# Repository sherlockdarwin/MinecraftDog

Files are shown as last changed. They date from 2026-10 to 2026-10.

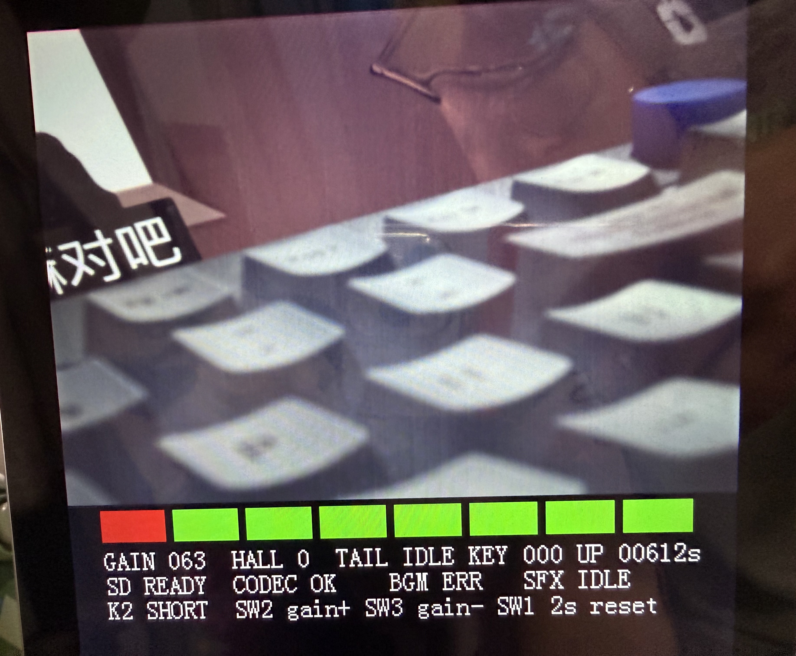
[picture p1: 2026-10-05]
显示屏显示的.JPG

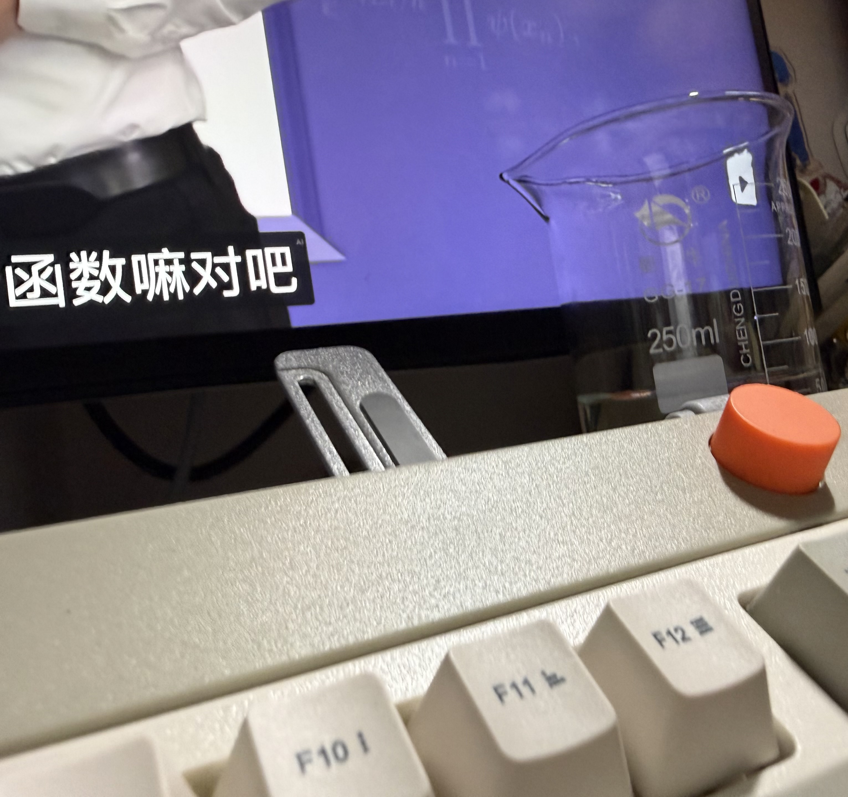
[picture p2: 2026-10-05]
现实.JPG

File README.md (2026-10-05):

# MinecraftDog：基于安路 PH1P35 的跟随避障机器狗

> 2026 嵌入式芯片与系统设计竞赛 · FPGA 赛道（安路选题二）｜TD 6.2.1 + Verilog｜更新 2026-10-05（晚）

---

## 0. AI 交接（新会话先读这一节）

**当前状态**：TD 工程 `mcproject_code/MinecraftDog_FPGA.al`（PH1P35MDG324-3，顶层 `mctop`）。2026-10-05 第一次接屏 + 相机 + 尾巴 + 霍尔上板：**屏幕花屏（竖条纹、字被压扁、整屏抖）、尾巴上电没回中、霍尔 = 1 尾巴也不动**。已按下面改完（仿真全部通过、TD 完整流程通过），**还没再上板**。

**已完成**（统一说明；每块的文件、接线、用法、排错在对应文档里）：

| 模块 | 内容 | 文档 |
| --- | --- | --- |
| 视频通路 | IMX415 → MIPI 4 lane → 取窗 800×560 → 去马赛克 + 白平衡（逐帧算增益）→ DDR2 四缓冲 → 10.1" 800×1280 DSI 屏；竖屏，**上半相机 / 中间状态带（8 个状态方块 + 3 行黑底白字）/ 下半留给避障**；DSI 水平消隐照抄厂商例程；3 个 LED 指示初始化进度 | `src/doc/video_pipeline.md` |
| 人机 | 三键：SW2 / SW3 短按 = 相机增益 ±1；SW1 按住 2 秒整机复位（没有翻页、没有音频页） | `src/doc/hmi_tail.md` |
| 尾巴 | ZDT X42S 步进电机（UART **只发不收**）：上电约 1 秒自动**单圈就近回零**（驱动器转到它存的零点 = 正中）、摇摆一个来回 | 同上 |
| 霍尔 + 行为层 | 霍尔传感器（磁铁靠近 = 1）判断喂食：尾巴摇一个来回，磁铁还在就再摇一个来回；同时进食音效播一遍（播放中不重复触发） | 同上 |
| 音频 | TF 卡 WAV → ES8388 → 喇叭口：`1.wav` 背景音乐上电自动循环（J12 左）、`2.wav` 进食音效（J11 右）、`3.wav` 狗叫（预留）；两路同时播；音量最大；8~48.8 kHz 自动重采样；没有按键操作 | `src/doc/audio.md` |
| 接线 | 步进 TX（只一根线）、霍尔输入接哪些脚，怎么改脚 | `src/doc/pinout.md` |

**验证状态**

- 仿真：20 个测试台（含最慢的 `tb_top` / `tb_audio` / `tb_fb`）在最终文件上全部通过（2026-10-05）。这次新写 / 重写的（白平衡、尾巴、文字面板、台架、串口）都做过突变检查（故意改坏 RTL，看测试台会不会报错），没抓到的都是等价突变，记在 `hmi_tail.md` §7。
- TD 完整流程（综合 + 布局布线 + bit）：**SWNS +1.105 ns、HWNS +0.020 ns，0 违例**；**slice 52%**（上一版 75%）、LUT 47%、寄存器 26%、ERAM 38%、DSP 20%；bit 在 `src/boot/MinecraftDog_FPGA.bit`。省下的 23 个百分点几乎全来自白平衡（原来每个像素都做两次流水线除法，改成每帧算一次）。
- **屏幕**：改的是最可疑的那处（水平消隐），**初始化脚本是否匹配这块屏仍没验证**；还花屏就要商家的初始化代码（`video_pipeline.md` §6）。

**已删除（记录）**：
- 轮子电机：曾经做过 TB6612 双路电机驱动 + 双编码器测速 + 底盘动作命令 + 台架底盘页；轮子控制改放在另一块单片机上，已全部删除。旧版本在 git 提交 `a8d9f01`「有电机」。
- 台架音频页（2026-10-05）：翻页、选曲 / 播放 / 停止、2 秒测试音、背景音乐开关，以及屏幕上的音频页（错误码、缺数据次数、曲目号）。规则已定，不用在板上调；`mc_audio` 的 `I_bgm_en` / `I_sfx_stop` / `I_sfx_tone` 端口和播放器里的测试音一起删了。
- 步进驱动器的串口接收（2026-10-05）：只留 FPGA → 驱动器一根线，`mc_uart_rx` 和应答计数删了；尾巴的「复位 / 标定零点 / 停止」命令口也删了（只剩摇摆 + 上电自动回零）。
- 白平衡的两个流水线除法器（`divider` IP）：被「每帧算一次」的小除法器替代。

**待办**：见 §3。

**规则**

1. 工具：TD（综合、布局布线、下载、ChipWatcher），Verilog-2001（厂商 MIPI 封装用 SystemVerilog）。仿真用 Icarus Verilog（用户已同意安装：`winget install Icarus.Verilog`；换机器装之前先问）：`bash tools/sim.sh` 跑 `src/sim/` 的测试台，默认的 17 个约 25 分钟，跳过最慢的 `tb_top`（约 15 分钟）、`tb_audio`（约 30 分钟）、`tb_fb`（约 2 分钟）；`ALL=1` 全跑（顺序约 1.2 小时）；长仿真放后台，多个并行时各设 `SIM_OUT=<目录>`。厂商的 MIPI 收发、ISP、DDR 控制器没有仿真，靠复用已验证模块 + `tools/td_build.sh` + 上板后用 LED / 状态方块 / ChipWatcher。
2. TD 开着工程时（`mcproject_code/.lock.f` 存在）**不要改 `.al`，不要移动 / 重命名已加入工程的文件**，否则 TD 可能用内存里的版本覆盖；只改文件内容没问题。
3. 在 `src/` 下增删文件后：关 TD → `bash tools/gen_al.sh` → `bash tools/td_build.sh`（在临时目录跑，TD 开着也能用）。**新增 RTL 必须配测试台**（`src/sim/tb_*.v`，并在 `tools/sim.sh` 的 `rtl_for` 登记），而且要做**突变检查**：故意改坏一处，测试台必须 FAIL；接线层（顶层把模块连起来）也要测；确认突变真的改到了；分清"测试台漏洞"和"等价突变"；测试台超时设短（改坏的 RTL 常常卡死）。
4. IP 放 `src/ip/<名>/`（TD 的 Tools → IP Catalog 生成；厂商 IP 整个目录原样复制，目录名不能改）。唯一手改：`w8_d1024_rom` 的 `INIT_FILE` 指向我们的 mif；屏幕初始化脚本改 `rtl/video/disp/panel/ili9881c_k101_init.txt` 后运行 `make_rom.ps1`。
5. 厂商模块尽量不改，改了记进 `video_pipeline.md` §9；自写模块加 `mc_` 前缀，一个文件一个模块，文件名 = 模块名。
6. 编码：UTF-8；厂商源码注释多为 GBK（读之前 `iconv -f GBK -t UTF-8`）；含中文的 PowerShell 5.1 脚本必须带 UTF-8 BOM。
7. 命名沿用米联客：`I_` 输入、`O_` 输出、`IO_` 双向、`S_` 内部信号、`_n` 低有效。
8. 时序逻辑只用 `<=`。自己的模块用异步复位、同步释放（`mc_rst_sync`）；厂商模块直接接 PLL lock。跨时钟域：单比特 `mc_sync_bits` 打两拍，多比特用异步 FIFO 或握手。
9. 周期性任务（PID、串口解析、按键扫描）用 `mc_tick` 的节拍脉冲做使能，不要另写分频计数器，不要造门控时钟。
10. TD 的坑：**TD 的工作目录必须是工程目录 `mcproject_code/`**——双击 `MinecraftDog_FPGA.al` 打开，或先 `cd mcproject_code` 再 `td.exe MinecraftDog_FPGA.al`；从开始菜单启动再 File → Open 的话，TD 找不到 DDR2 IP 自带的约束（生成的 `settings.cfg` 里没有 `IpADCList`，命令行实测工作目录不对就是这样），综合报 `SYN-8534 Can not get the inst ... please add inst constraint`（`tools/td_build.sh` 不受影响）；输入脚的 adc 不能写 `DRIVESTRENGTH`；DDR 端口 `ddr_cke / ddr_odt / ddr_cs_n / ddr_ck_p / ddr_ck_n` 必须声明成 `[0:0]`；加密的 DSI 打包核里藏着 `w32_d512_fifo`、`w8_d1024_fifo` 两个 IP，漏了会报 "black box"；`.al` 里每个文件的 `CompileOrder` 不能重复。
11. 取窗硬约束：`CROP_Y0` 必须是奇数（Bayer 相位）；`WIN_W` 是 16 的倍数且 `WIN_W×WIN_H` 是 1280 的整数倍（帧缓存突发长度）。
12. **用词：Verilog 里没有"写函数然后调用"。** 功能写成**模块**，用的地方**例化**；"调用" = 给输入端口一个命令（电平，或脉冲 + `busy/done`），"返回值" = 读输出端口；`delay_ms` 式阻塞等待 = 状态机里数 `mc_tick` 节拍。接口速查：`hmi_tail.md` §5。
13. 按键：SW2 / SW3 短按 = 相机增益 ±1，**SW1 按住 2 秒整机复位**，其余没有功能（`hmi_tail.md` §4）。
14. 屏幕版面（上半相机窗口、中间状态带、下半避障区）只在 `mctop.v` 配置区定义（只做竖屏）。版面图：`video_pipeline.md` §4。**DSI 的水平消隐（24/136/160）和厂商例程一致，不要压缩**（压缩过一次，上板花屏）。
15. 对用户：用中文，概念用 STM32 类比，给 TD 的具体菜单步骤；文档精简；写完代码要讲清架构、每个文件做什么、怎么接线。

---

## 1. 比赛和硬件

| 项 | 内容 |
| --- | --- |
| 截止 | **2026-11-04 18:00** 线上提交作品报告 + 视频（www.socchina.net）；决赛 11-20 ~ 22，南京，现场有 FPGA 编程考核 |
| 选题 | 安路选题二：PH1P35 实时图像处理，结合移动平台，根据识别结果做外部控制 |
| 规则 | 不能用非安路 FPGA；主控和算法放 FPGA（片内 RISC-V 也可）；UWB、超声波等成品模块只当传感器 |
| 得分点 | MIPI 采集 + 实时显示、至少一种 FPGA 图像算法、OSD（**必须带"安路"Logo**）、长时间稳定运行；加分：目标跟踪 + 坐标叠加、运动检测、延迟可视化、AE/AWB、多算法切换 |

| 硬件 | 说明 |
| --- | --- |
| 板子 | 米联客 MLKPAI-F02 底板 + FC02 核心板：PH1P35MDG324（LUT4 38k、DFF 42k、DSP 40、ERAM 108×20 Kb）、合封 DDR2 512 Mb、MIPI D-PHY ×2（CSI 收 / DSI 发）、CEP 排针 36 个 3.3 V IO；没有 HDMI；Type-C 下载 / 供电 5V/3A |
| 摄像头 | MLK-CAM002-IMX415：MIPI CSI-2 4 lane RAW10；I2C 0x34；INCK 24 MHz；2×2 binning 1920×1080，每 lane 891 Mbps；M12 镜头 f 4.2 mm，视场 H72°/V56° |
| 屏幕 | 米联客 10.1" MIPI DSI：**800×1280 竖屏**，ILI9881C，4 lane |
| 尾巴 | ZDT X42S 第二代闭环步进电机（串口 TTL 版，Emm 固件，UART 115200 只发，地址 1，16 细分），摆幅 ±30°；上电单圈就近回零 |
| 轮子 | **不在 FPGA 里**：轮子的电机驱动、编码器和速度环都放在另一块单片机上 |
| 音频 | TF 卡 → 板载 ES8388 → 板载 TT8642 功放 → 喇叭口 J12（左）/ J11（右）或耳机口 J3 |
| 传感器 | 霍尔模块（喂食检测，磁铁放在食物模型上）；UWB 模组、超声波：**待资料，先不写** |
| 电源 | 2S 锂电池 → 5 V/3 A 降压给开发板；所有地连在一起（包括轮子单片机） |

管脚、接线、改脚：`pinout.md`；时钟：PLL `mcsys_pll` 输入 25 MHz，输出 100 MHz（主逻辑）/ 24 MHz（相机）/ 52.173913 MHz（DSI 参考）/ 10 MHz（面板 LP 配置），各时钟域之间按异步处理（`mc_timing.sdc` 的 `set_clock_groups`）。

和 C 工程（TI2026H）的对应：`main()` + SysConfig → `mctop.v` + `pin/mc_pin.adc`；定时器 + 任务表 → `mc_tick` 脉冲 + 各自用 tick 做使能的 always 块（并行，互不阻塞）；`Key()` → `mc_key`；`OLED_Show*` → `mc_osd_dash`（版面由 `tools/gen_osd_dash.pl` 生成）；`Stepper_*` → `mc_tail`（只发不收）。

## 2. 数据流

```
IMX415 ─MIPI─► 取窗 → 去马赛克 → AWB ─► DDR2 四缓冲 ─► mc_mixer（上半相机 + 状态带）─► DSI ─► 屏幕             ◄ 已完成
                └─► 避障分析（并联一路抽取，160×90 流水线）→ 16 个扇区的可通行深度 → 屏幕下半：处理画面 + 画框   ◄ 待办
霍尔 ─► mc_hall ─► mc_behavior ─┬─► mc_tail（尾巴，UART 只发）◄ 已完成
                                └─► mc_audio（进食音效）       ◄ 已完成
UWB / 超声波 ─► （距离、方位）─► mc_behavior / 决策 ─► 速度 / 方向命令 ─► 轮子单片机（接口待定）                ◄ 待办
```

## 3. 待办

1. **上板验证**（按顺序）：屏幕（这次改了水平消隐；还花屏就要商家这块屏的初始化代码，`video_pipeline.md` §6）→ 相机出图（稳定、不卡顿）→ 尾巴（先在驱动器菜单设回零零点，`hmi_tail.md` §3；方向与摆幅 `TAIL_LEFT_CCW`、`TAIL_GEAR_X100`）→ 霍尔 → 音频（音量最大，破音就把 `AUD_SPK_VOL` 改回 30）→ 摄像头安装高度和俯角。
2. **避障模型 + 画框（屏幕和相机稳定以后再做，还没开始）**：只做避障必需的图像运算（§4），处理后的画面 + 可通行框画在**屏幕下半部分**（v 720~1279，800×560，和相机窗口一样大；`mc_mixer` 叠加）；OSD 要带安路 Logo。
3. **UWB（等资料齐了再写）**：串口解析出距离 / 方位；接 `mc_behavior`：距离 < 5 m 时摇尾巴（`I_near`）；检测不到 / 太远时播 `3.wav` 狗叫（`I_bark`）；跟随控制。
4. 超声波近距兜底。
5. 决策状态机（安全 > 避障 > 跟随 > 报警），输出方向 / 速度命令给轮子单片机（接口待定，串口最简单；速度环 PID 在那块单片机上）。
6. 小改进（有余力再做）：重采样改线性插值；背景音乐循环衔接处的短停顿；屏幕稳定以后把 DSI 提到约 60 Hz（`video_pipeline.md` §7）。
7. **资源**：slice 用了 52%，还剩约 48%（约 10000 个 slice）给避障流水线。大头（综合后 LUT + 进位）：相机接口 `mc_cam_if`（去马赛克 + 白平衡 + MIPI 收）、帧缓存 + DDR2 控制器、音频约 2500（`mc_fat32` 约 1100、两个播放器约 700）、显示接口约 800、文字面板约 250。

## 4. 避障需要的图像运算（只做必要的，其余不管）

方案：单目"地面外观 + 列扫描"（Ulrich & Nourbakhsh 2000），整条链都是行缓存流水线，不占 DDR，PH1P35 放得下（Fast-SCNN 之类分割网络放不下）。前提：地面大致平坦且颜色和障碍不同；摄像头下俯 15° ~ 25°。

| # | 运算 | 干什么 |
| --- | --- | --- |
| 1 | 抽取 + 均值 | 完整视场（取窗之前）→ 2×2 抽取 → 6×6 均值 → 160×90 |
| 2 | RGB → YCbCr（移位加法） | Y 找边缘；Cb / Cr 判断地面颜色（对阴影不敏感） |
| 3 | Sobel 边缘（3×3 窗口，前面可加 3×3 平滑） | 地面和障碍颜色接近时靠边缘分开 |
| 4 | 地面颜色模型 | 画面底部中间梯形区域统计 Cb / Cr 均值 ± 余量；超声波说前方 50 cm 内没东西才更新 |
| 5 | 二值化 | 颜色不像地面 **或** 边缘强 → 障碍 = 1 |
| 6 | 腐蚀 → 膨胀（开运算） | 去掉地砖缝、木纹、噪点 |
| 7 | 列扫描 | 每列从下往上第一个障碍点 → 可通行高度；160 列合并成 16 个扇区取最小 |
| 8 | 行号 → 距离 | 查表（地上每隔 10 cm 做标记，记行号） |
| 9 | 时域平滑 | 和上一帧取最小 / 平均，防闪烁 |
| 10 | 画框 / 色条 / Logo | 每帧消隐期在 16 个扇区深度上找最大矩形（宽度要容得下车身）；`mc_mixer` 逐像素判断是否在框线上；窗口内坐标 = 传感器坐标 − 窗口左上角（`CROP_X0_GRP×4`、`CROP_Y0`）；框坐标从分析时钟域用握手 / 双缓冲交给像素时钟域 |

已有的：去马赛克、白平衡（`awb`）、手动增益（台架第 0 页）。每一步先写测试台（用静态图片作输入）。

## 5. 参考项目和论文

| 项目 / 论文 | 借鉴什么 |
| --- | --- |
| [maojinxiang/FPGA-ANLU-National-First-Prize](https://github.com/maojinxiang/FPGA-ANLU-National-First-Prize)（首奖项目：HX4S20C + OV5640 + 640×480 HDMI，核心 `Main/q3q4/import/udp_cam_ctrl.v`） | 16 种图像效果里**只有灰度、二值化、Sobel、腐蚀、膨胀**直接能用；所有效果放一个模块用选择信号切换、Sobel / 腐蚀 / 膨胀共用 3×3 窗口的结构。它是 EG4 工程，代码不能直接搬；没有地面模型、列扫描、距离换算 |
| Ulrich & Nourbakhsh，*Appearance-Based Obstacle Detection with Monocular Color Vision*（AAAI 2000，[摘要页](https://mlanthology.org/aaai/2000/ulrich2000aaai-appearance)） | 本方案的原型：按颜色外观把每个像素分成"地面 / 障碍"，前方一块地面作参考区、边走边更新 |
| Angelo Jacobo：[FPGA_RealTime_and_Static_Sobel_Edge_Detection](https://github.com/AngeloJacobo/FPGA_RealTime_and_Static_Sobel_Edge_Detection)（MIT） | Verilog 流水线 Sobel：行缓存 + 3×3 窗口 + 阈值的写法（Xilinx 的 PLL / SDRAM 文件不用管） |
| Machado 等，*Vision-based robotics using open FPGAs*（Microprocessors and Microsystems 103，2023，[条目页](https://burjcdigital.urjc.es/items/fd325d26-45aa-4980-aa14-6e47b91387c9/full)） | 开源 Verilog 视觉机器人模块库（图像处理块 + 反应式控制块），演示彩色目标跟随；条目页没给代码仓库链接，要自己再找；"按颜色跟随"可当 UWB 跟随的备份 |
| *A Monocular Vision Sensor-Based Obstacle Detection Algorithm for Autonomous Robots*（Sensors 16(3):311，2016，[全文](https://www.mdpi.com/1424-8220/16/3/311)） | 逆透视映射 + 地面外观模型：对应"行号 → 距离"查表和地面模型（后面的马尔可夫随机场太重，不用） |
| *Real-Time Freespace Segmentation on Autonomous Robots…*（[arXiv 1902.00842](https://arxiv.org/pdf/1902.00842)） | 目标和我们一样（可通行区域）但用神经网络，跑不动；只当"输出长什么样"的参考 |
| Linux 内核 [`panel-ilitek-ili9881c.c`](https://github.com/torvalds/linux/blob/master/drivers/gpu/drm/panel/panel-ilitek-ili9881c.c) | ILI9881C 初始化序列和显示时序的公开参考（本工程用 K101-IM2BYL02 那一份） |
| 安路官方样例 https://pan.baidu.com/s/12hjB7BiAxT3CIVqzh4Amnw（提取码 Q614） | HX1P35A 平台（也是 PH1P35MDG324）的 MIPI、边缘检测、OSD 样例；评分标准在 `../选题/` |

（后四项和 Machado 的条目是检索结果摘要，没有逐个读源码，用之前自己判断。）

## 6. 目录

```
MinecraftDog/
├── README.md
├── tools/        td_build.sh（命令行跑 TD 完整流程）、gen_al.sh（重新生成 .al，TD 要关）、sim.sh（跑测试台）、gen_osd_dash.pl（生成屏幕状态面板 mc_osd_dash.v）、mk_sd_test_image.pl（生成测试用 FAT32 卡镜像）、render_pdf.ps1（PDF 页转 PNG）、gen_font.sh（生成字库）
└── mcproject_code/               TD 工程根目录（MinecraftDog_FPGA.al 在这里）
    └── src/
        ├── rtl/      mctop.v（顶层 + 配置区）、system/（复位、节拍、同步器、长按复位）、hmi/（按键、台架）、comm/（串口发送）、tail/（尾巴）、
        │             sensor/（霍尔）、app/（行为层）、audio/（TF 卡 WAV → ES8388）、video/（cam 相机、rx MIPI 接收、isp、fb 帧缓存、disp 显示接口 + 合成器、osd 文字层）
        ├── ip/       TD 生成的 IP，一个 IP 一个子目录
        ├── pin/      mc_pin.adc（管脚）、mc_timing.sdc（时序）
        ├── sim/      20 个测试台 tb_*.v + stubs/（顶层集成测试用的视频替身、白平衡延迟线 RAM）+ models/（TF 卡、I2C 从机行为模型）
        ├── boot/     验证过的 .bit
        └── doc/      pinout.md 接线｜video_pipeline.md 视频通路 + 版面｜hmi_tail.md 按键 / 台架 / 尾巴 / 霍尔 / LED｜audio.md 音频
```

参考资料（路径相对 `FPGA/reference/`）：`02_F02_FC02_PH1P35/01_start/02_peripheral_demo/02_peripheral_demo/08_csi_dsi_cs500_7cun/`（视频通路底座：MIPI RX、ISP、DDR2、DSI；`td_project/*.sdc` 是多时钟约束范本）；`07_ddr_test`、`09_aud8388_loop`（DDR2 用法、ES8388 配置）；`02_hardware/…/MLKPAI-F02开发平台硬件使用手册.pdf`（管脚表）和 `…/02_原理图/MLKPAI-F02底板.pdf`（P05 AUDIO 页、TF 卡座；渲染某页：`powershell -File tools/render_pdf.ps1 -Pdf <pdf> -Page <页号> -Out <png>`）；`06_MLK-CAM002-IMX415/`（IMX415 配置、4-lane 解包、`摄像头调节心得.docx`）；`显示屏1~3.png`（10.1" 屏的 40P 管脚、尺寸）；`TI2026H题code/`（旧 C 工程：PID、任务调度，可参考参数；轮子单片机那边用得上）。不用看：`XILINX/`、`F20_CM02_3EG_1_1/`、`soc_prj/`（Xilinx 工程）。

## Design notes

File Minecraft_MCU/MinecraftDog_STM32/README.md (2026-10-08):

## MinecraftDog STM32F103RCT6

### 功能

跟随 + 避障的决策全在 FPGA, STM32 只做传感器和电机驱动:

1. **UWB 定位**: 三个基站(左 / 前 / 右)各接一个串口, 中断收字节, 解 0x2001 定位帧(37 字节, XOR 校验)。
   取角度最靠近自己正前方的那个基站, 换算成车体坐标(左负右正)的角度 + 距离; 500 ms 没新数据 = 收不到 UWB。
2. **发给 FPGA**: 有新 UWB 数据就用 DMA 发主人的角度、距离; 收不到 UWB 就发"丢失"。
3. **收 FPGA 的命令**: DMA 环形缓冲收两个轮子的 PWM, 解包后驱动电机。
4. **停车保护**: 收不到 UWB / 200 ms 没收到完整的 FPGA 帧 / FPGA 发来停车, 任何一条成立就关电机锁停车。
5. **电机驱动**: 两路 PWM(9 kHz, 0~8000) + 4 个方向脚, 带死区补偿和方向极性开关。
6. **编码器**: TIM8 / TIM2 硬件计数, 速度和里程函数都在 `encoder.c`, 现在控制里没用到。
7. **按键试电机**: KEY1 前进 3 秒、KEY2 后退 3 秒, 不用接 FPGA。
8. **LED**: 和 FPGA 通 = 1 秒闪一次, 不通 = 快闪。

### 目录

| 位置 | 内容 |
| --- | --- |
| `Core/` `Drivers/` | CubeMX 生成。`main.c` 只在 USER CODE 里调 `bsp_init()` / `Scheduler_Run()` |
| `SYSTEM/` | `AllHeader.h`、`bsp.c`(模块初始化)、`delay.c`(SysTick 微秒延时 + 秒表)、`task.c`(协作式调度表, 1 ms 时基 = `HAL_GetTick()`) |
| `HARDWARE/MLK/` | FPGA 串口 (USART3, DMA 收发), 解包变量在`fpgamlk.c` 顶部 |
| `HARDWARE/UWB/` | 三个 UWB 基站 (USART2 / UART4 / UART5, 接收中断) |
| `HARDWARE/MOTOR/` | 电机 PWM + 方向、编码器 |
| `HARDWARE/KEY/` | KEY1 / KEY2 |
| `ALGORITHM/` | 本地跟随`follow.c`, 已停用, 保留备查 |

OLED 没移植 (STM32 版没留 OLED 引脚)。

### 引脚

| 功能 | 引脚 | 外设 |
| --- | --- | --- |
| FPGA | PB10 TX -> FPGA CEP 脚 4; PB11 RX <- CEP 脚 3; GND 接 CEP 脚 2 | USART3, RX DMA1 CH3 (Circular), TX DMA1 CH2 |
| UWB 左 / 前 / 右 | PA3 / PC11 / PD2 收 (PA2 / PC10 / PC12 发, 预留) | USART2 / UART4 / UART5, 接收中断 |
| 左 / 右轮 PWM | PA6 / PA7 | TIM3 CH1 / CH2, 9 kHz, 0~8000 |
| AIN1 AIN2 BIN1 BIN2 | PB12 PB13 PB14 PB15 | GPIO 输出 |
| 左编码器 A / B | PC6 / PC7 | TIM8 编码器 |
| 右编码器 A / B | PA15 / PB3 | TIM2 编码器 (部分重映射, 要 SYS = Serial Wire) |
| KEY1 / KEY2 | PC9 / PC8 | 输入上拉, 按下 = 低 |
| LED | PA8 | GPIO_Output, Label =`LED` (没有这个 Label 时 `Task_LED` 什么也不做) |
| SWD | PA13 / PA14 | |

### 任务

| 任务 | 周期 | 做什么 |
| --- | --- | --- |
| `Task_UWB_Poll` | 5 ms | 解析 UWB 帧 |
| `Task_FPGA_Rx` | 5 ms | 解 FPGA 帧 (`#+3000-0500*` / `#S*`); 串口出错时重启接收 DMA |
| `Task_Motor_Drive` | 5 ms | 按 FPGA 命令驱动电机; UWB 丢 / 200 ms 没帧 /`#S*` 立即停车; 按键试电机 |
| `Task_FPGA_Tx` | 20 ms  | 新 UWB 数据发`$l12350&`, 收不到 UWB 发 `$S&` (100 ms 重发) |
| `Task_Key_Scan` | 10 ms  | 按键消抖 |
| `Task_LED` | 100 ms | 和 FPGA 链路通 = 1 秒闪一次, 不通 = 快闪 |

**试电机方向** (不用接 FPGA): KEY1 = 两轮 +3000 前进 3 秒, KEY2 = 两轮 -3000 后退 3 秒, 测试中再按任一键停。
哪个轮子转反了, 改 `motor.h` 的 `MOTOR_L_DIR_INVERT` / `MOTOR_R_DIR_INVERT`。

### 和 FPGA 的通讯协议

UART 115200 8N1, ASCII, **位数不够前面补 0**。
接线: FPGA CEP 脚 3 (FPGA 发) -> **PB11**; **PB10** -> CEP 脚 4 (FPGA 收); GND 接 CEP 脚 2。

| 方向 | 帧 | 含义 | 什么时候发 |
| --- | --- | --- | --- |
| STM32 -> FPGA | `$` + `l`/`r` + 角度 2 位 + 距离 3 位 + `&` | 主人在左(`l`) / 右(`r`) 多少度、多远(cm)。例`$r00150&` = 正前方、150 cm。角度超过 99° 发 99, 距离超过 999 cm 发 999 | 每次有新 UWB 数据(最快 20 ms 一帧) | |
| STM32 -> FPGA | `$S&` | 收不到 UWB | 刚丢时立刻发, 之后每 100 ms 一帧 |
| FPGA -> STM32 | `#` + 左轮(符号 + 4 位) + 右轮(符号 + 4 位) + `*` | 两个轮子的 PWM, 正 = 前进, 满量程 8000 (就是`PWM_Control_Car(左, 右)` 的参数)。例 `#+3000-0500*` = 左 +3000、右 -500 | FPGA 每 20 ms 一帧 |
| FPGA -> STM32 | `#S*` | 马上停车 | 停车期间每 20 ms 一帧 |

- 超时: FPGA 那边 300 ms 收不到 `$…&` 就当 UWB 丢了; STM32 这边 200 ms 收不到完整的 `#…*` 就停车。
- 解包规则 (`fpgamlk.c`): 收到 `#` 就重新开始一帧, 帧外的字节丢掉; `S` 大小写都行;
  格式不对的整帧丢掉 (计数在 `g_fpga_error_count`); 超过 ±8000 的按 ±8000 算。
- 解包结果 (`fpgamlk.c` 顶部, 调试时在 Live Expressions 里看):

- [ ] 变量含义`g_fpga_left_pwm` / `g_fpga_right_pwm`最近一帧的左 / 右轮命令`g_fpga_stop`1 = 最近一帧是`#S*` (上电还没收到帧时也是 1)`g_fpga_last_ms` / `g_fpga_frame_count`最近一帧的时刻 / 累计帧数`g_fpga_error_count` / `g_fpga_uart_error_count`格式错的帧数 / 串口硬件错误次数 (每次都会自动重启接收)`g_fpga_uwb_lost` / `g_fpga_tx_angle_deg` / `g_fpga_tx_distance_cm` / `g_fpga_tx_count`最近发给 FPGA 的内容和累计发出的帧数

### CubeMX 里不能改掉的设置

- USART3_RX DMA Mode = **Circular**; USART3 global interrupt **打开** (DMA 发送靠它结束, 串口出错也靠它报告)。
- USART2 / UART4 / UART5 global interrupt 打开。它们的中断在 `stm32f1xx_it.c` 的 USER CODE 0 里直接调
  `UWB_IRQHandler()` 后 `return`, 不走 HAL。
- TIM3 Period = 7999 (PWM 满量程 8000, 和 FPGA 发来的命令同一个刻度)。
- 重新生成代码时 Project Manager 里要保持 "Keep User Code when re-generating"。

### 工程设置 (CubeMX 重新生成后还在)

- `.cproject` 的源码目录: `Core` `Drivers` (CubeMX 自带) + `ALGORITHM` `HARDWARE` `SYSTEM`。
- include 路径: `../` `../SYSTEM` `../HARDWARE` `../HARDWARE/MOTOR` `../HARDWARE/UWB`。
- CubeMX 重新生成时会把"整个工程根目录当源码"这种设置删掉, 只保留按文件夹加的源码目录,
  所以 **新建 .c 文件要放进这几个文件夹里**, 别放工程根目录 (放了不会被编译)。
- 新建文件夹要编译: Properties -> C/C++ General -> Paths and Symbols -> Source Location -> Add Folder。
- 重新生成前先关掉编辑器里打开的 `main.c` 等 CubeMX 文件, 生成完在工程上按 F5 刷新;
  不然编辑器里的旧内容一保存, 就会把 USER CODE 里的 `bsp_init()` / `Scheduler_Run()` 盖掉。

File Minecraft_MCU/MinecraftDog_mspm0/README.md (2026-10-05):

## MinecraftDog MSPM0G3507 base project

This project provides a ready-to-call base layer for the drive motors,
quadrature encoders, SSD1306 OLED, and three ALX-AOA-FIT UWB anchors. All
periodic work is registered in `task.c`; `main()` only initializes the BSP and
runs the cooperative scheduler.

### Follow controller

`ALGORITHM/follow.c` implements a differential-drive distance/heading
controller. `Task_Follow_Control` runs it every 20 ms. The distance error
produces forward PWM, the signed UWB azimuth produces turning PWM, and the two
commands are mixed into left/right wheel commands. Forward PWM increases with
distance and is reduced as the heading error grows; at 90 degrees the robot
pivots instead of driving farther away. A command ramp limits sudden speed
changes.

The controller is disabled after reset for safe bench testing. Start and stop
it explicitly:

```c
Follow_Enable(1U); /* allow automatic following */
Follow_Enable(0U); /* immediate stop and motor lock */
```

Two public condition flags are ready for later FPGA communication:

- `g_follow_stop_flag == 1`: fresh target distance is at most 300 cm.
- `g_follow_lost_flag == 1`: target is missing/stale or farther than 2000 cm.

Both conditions stop the motors immediately. The gains, limits, and distance
thresholds are centralized in `ALGORITHM/follow.h` for vehicle tuning.

### Keys

Three active-low keys are sampled by `Task_Key_Scan` every 10 ms. The driver
uses a non-blocking state machine with 20 ms debounce and an 800 ms long-press
threshold. A long press is reported once while held and is not also reported as
a short press on release. Events are consumed through `KEY_TakeShortPress()`,
`KEY_TakeLongPress()`, or the `Key1_...`/`Key2_...`/`Key3_...` convenience
functions.

### UWB protocol

- Electrical interface: 3.3 V TTL UART, 115200 baud, 8 data bits, 1 stop bit,
  no parity, no hardware flow control.
- Location command: `0x2001`, 37-byte big-endian frame beginning with four
  `0xFF` bytes. The final byte is the XOR of all preceding bytes.
- The driver checks header, length, command, protocol version, and checksum.
- UART interrupts only enqueue bytes. `Task_UWB_Poll` parses them every 5 ms.
- `Task_UWB_Display` refreshes the blocking OLED once every 1000 ms.
- Measurements older than 500 ms are treated as unavailable.

The three antenna boresight offsets default to left `-90 deg`, forward `0 deg`,
and right `+90 deg`. Adjust `UWB_*_MOUNT_OFFSET_DEG` in
`HARDWARE/UWB/uwb.h` if the physical mounting angles differ. The fused result
uses the fresh anchor with the smallest absolute local azimuth, keeping the
selected measurement near the accurate center of its 120-degree sector.

```c
UWB_Target target;

if (UWB_GetTarget(Get_Time(), &target)) {
    /* target.azimuth_deg: vehicle-relative, left < 0, right > 0 */
    /* target.distance_cm: selected anchor-to-tag distance */
}
```

### Pin map

| Function | MSPM0G3507 pin | External connection |
| --- | --- | --- |
| UWB left TX / RX | PA21 / PA22 | MCU RX PA22 connects to anchor TX |
| UWB forward TX / RX | PA17 / PA18 | MCU RX PA18 connects to anchor TX |
| UWB right TX / RX | PA0 / PA1 | MCU RX PA1 connects to anchor TX |
| OLED I2C SDA / SCL | PA28 / PA31 | SSD1306 SDA / SCL |
| Motor PWM left / right | PA10 / PA11 | Driver PWM inputs |
| Motor AIN1 / AIN2 | PA12 / PA15 | Left motor direction inputs |
| Motor BIN1 / BIN2 | PA16 / PB17 | Right motor direction inputs |
| Encoder left A / B | PB13 / PB14 | Both-edge GPIO interrupts |
| Encoder right A / B | PB15 / PB16 | Both-edge GPIO interrupts |
| Key 1 / Key 2 / Key 3 | PA26 / PA25 / PA24 | Active-low inputs with internal pull-ups |
| Reserved FPGA/MLK TX / RX | PA14 / PA13 | Existing UART3 configuration unchanged |

For every UWB module, connect grounds directly. The MCU-to-anchor TX wire is
optional for the current active-report protocol, but its pin is reserved so
future commands can use a full UART pair.

### Task registration

Add future periodic work only to the `tasks[]` table in `task.c`. Keep fast,
non-blocking parsing/control tasks before the 1000 ms OLED task.

## Original SDK project notes

### Peripherals & Pin Assignments

| Peripheral | Pin | Function |
| --- | --- | --- |
| SYSCTL |  |  |
| DEBUGSS | PA20 | Debug Clock |
| DEBUGSS | PA19 | Debug Data In Out |

## BoosterPacks, Board Resources & Jumper Settings

Visit [LP_MSPM0G3507](https://www.ti.com/tool/LP-MSPM0G3507) for LaunchPad information, including user guide and hardware files.

| Pin | Peripheral | Function | LaunchPad Pin | LaunchPad Settings |
| --- | --- | --- | --- | --- |
| PA20 | DEBUGSS | SWCLK | N/A | <ul><li>PA20 is used by SWD during debugging<br><ul><li>`J101 15:16 ON` Connect to XDS-110 SWCLK while debugging<br><li>`J101 15:16 OFF` Disconnect from XDS-110 SWCLK if using pin in application</ul></ul> |
| PA19 | DEBUGSS | SWDIO | N/A | <ul><li>PA19 is used by SWD during debugging<br><ul><li>`J101 13:14 ON` Connect to XDS-110 SWDIO while debugging<br><li>`J101 13:14 OFF` Disconnect from XDS-110 SWDIO if using pin in application</ul></ul> |

### Device Migration Recommendations
This project was developed for a superset device included in the LP_MSPM0G3507 LaunchPad. Please
visit the [CCS User's Guide](https://software-dl.ti.com/msp430/esd/MSPM0-SDK/latest/docs/english/tools/ccs_ide_guide/doc_guide/doc_guide-srcs/ccs_ide_guide.html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)
for information about migrating to other MSPM0 devices.

### Low-Power Recommendations
TI recommends to terminate unused pins by setting the corresponding functions to
GPIO and configure the pins to output low or input with internal
pullup/pulldown resistor.

SysConfig allows developers to easily configure unused pins by selecting **Board**→**Configure Unused Pins**.

For more information about jumper configuration to achieve low-power using the
MSPM0 LaunchPad, please visit the [LP-MSPM0G3507 User's Guide](https://www.ti.com/lit/slau873).

## Example Usage

Compile, load and run the example.

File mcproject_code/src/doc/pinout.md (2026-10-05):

# 引脚接线

外接的东西全部接在底板的 **CEP 排针**（2×20，间距 2.54 mm，所有 IO 都是 3.3 V，**不耐 5 V**）。脚 1 = 3.3 V，脚 2 = GND，脚 3~38 = 信号 `CEP_L1_P`、`CEP_L1_N` … `CEP_L18_N`（奇数脚 P，偶数脚 N，脚号 = 2×L + 1 或 2×L + 2），脚 39、40 空。脚号以板子丝印为准；FPGA 管脚号来自厂商引脚表 `06_CEP管脚定义表-J1.xlsx`。

## 1. 外设接线表

| 外设 | 信号（`mctop.v` 端口） | CEP 脚 | FPGA 管脚 | 接到外设的哪里 |
| --- | --- | --- | --- | --- |
| **步进电机（尾巴）UART，只发不收** | `O_step_tx` | 15 | E17 | 步进驱动器接线排上的 **R/A/H** 脚（串口 TTL 时 = 驱动器的 RX）。驱动器的 T/B/L 脚不接 |
| **霍尔传感器** | `I_hall` | 17 | B17 | 传感器模块的输出脚（**磁铁靠近 = 高电平，离开 = 低电平**） |

电源和地：
- 霍尔传感器模块：**用 CEP 脚 1 的 3.3 V 供电**（用 5 V 供电的话输出也是 5 V，会损坏 FPGA）。步进驱动器和开发板（以及以后的轮子单片机）的 GND 要连在一起。
- 步进驱动器（ZDT X42S 第二代，必须是**串口 TTL 版本**——手册 2.2.1；RS485 版本的 R/A/H 脚是差分电平，FPGA 直接接收不了）：自己的电源另接（10~29 V），**驱动器的 Gnd 脚接 CEP 脚 2（GND）**，不共地串口收不到。驱动器菜单保持出厂设置：`FWType = FW_Emm`、`P_Serial = UART_FUN`、`UartBaud = 115200`、`ID_Addr = 1`、`Checksum = 0x6B`、`MStep = 16`。第一次用要在驱动器菜单里设一次回零零点：先拔掉 R/A/H 那根线（不然 FPGA 上电 1 秒后会让它回旧零点）→ 驱动器断电 → 用手把尾巴拧到正中 → 驱动器上电 → 菜单 `0_Set` → `Set 0` → 插回 R/A/H 线（零点掉电不丢；上电时 FPGA 让驱动器"单圈就近回零"到这个点，见 `hmi_tail.md` §3）。
- 霍尔输入脚在 FPGA 里设了下拉：没接传感器时读到 0（不会误触发喂食）。你的模块如果是反过来的（磁铁靠近输出低），在 `mctop.v` 里把 `mc_hall` 例化处的 `.I_hall (I_hall)` 改成 `.I_hall (~I_hall)`，不用动接线（但下拉就变成"没接传感器 = 误触发喂食"，这种模块请外加上拉 / 自带推挽输出）。

其余 CEP 脚都空着，留给 UWB 串口、超声波、和轮子单片机的通信线等：

| CEP 脚 | 3 | 4 | 5 | 6 | 7 | 8 | 9 | 10 | 11 | 12 | 13 | 14 | 16 | 18 | 19 | 20 | 21 | 22 | 23 | 24 | 25 | 26 | 27 | 28 | 29 | 30 | 31 | 32 | 33 | 34 | 35 | 36 | 37 | 38 |
| --- | --- | --- | --- | --- | --- | --- | --- | --- | --- | --- | --- | --- | --- | --- | --- | --- | --- | --- | --- | --- | --- | --- | --- | --- | --- | --- | --- | --- | --- | --- | --- | --- | --- | --- |
| FPGA 管脚 | L15 | L16 | H14 | H13 | G15 | G14 | J15 | J16 | H17 | H18 | F17 | E18 | E16 | C18 | F18 | G17 | C17 | D18 | E13 | D13 | G16 | H16 | D15 | D14 | B16 | A15 | D16 | C16 | A17 | A18 | B15 | A14 | E15 | F15 |

## 2. 板载的（不用接线）

| 东西 | 管脚 |
| --- | --- |
| SW1 / SW2 / SW3（按下为低） | R10 / N2 / J14 |
| LED1 / LED2 / LED3（高电平亮） | K16 / K17 / J18 |
| 25 MHz 晶振 | C4 |
| 摄像头（CSI 口）：I2C SCL / SDA、INCK、复位 | T9 / U9 / V9 / V8；MIPI 差分对由硬核固定 |
| 屏幕（DSI 口）：背光 PWM、面板复位 | R11 / T10；MIPI 差分对由硬核固定 |
| ES8388：MCLK / SCLK / LRCK / DSDIN | F14 / K13 / C13 / J13；I2C SCL / SDA = A13 / B14；功放使能 K15 |
| TF 卡（SPI 模式）：CS / SCK / MOSI / MISO | E5 / D9 / C9 / E6 |
| 喇叭口 | 2 针排针 **J12（左声道，背景音乐）/ J11（右声道，音效）**，**两个口各接一个喇叭**（一个喇叭接一个口的两根线，两根都不接地） |

## 3. 要改引脚怎么改

引脚都写在 `src/pin/mc_pin.adc` 里，一行一个端口，例如霍尔传感器：

```
set_pin_assignment { I_hall } { LOCATION = B17; IOSTANDARD = LVCMOS33; PULLTYPE = PULLDOWN; }
```

- **直接改文本（最稳）**：TD 里展开 `constraint_1`，双击 `mc_pin.adc`，把 `LOCATION = ` 后面的管脚号换成上面"空着的 CEP 脚"表里的另一个（所有 CEP 脚都是 3.3 V，可以随便换），保存，再点 **Generate Bitstream**（TD 会自己判断重跑哪些步骤）。
- **用向导**：先 **Syn Opt → Read Design / Optimize Gate** 做完综合，再 **Tools → IO Constraint**，在表里改 Location 列，保存（步骤和截图见 `video_pipeline.md` §7）。
- 只改 `LOCATION` 就行，Verilog 里的端口名、`mctop.v` 都不用动。两个信号不能用同一个管脚；也不要用上面"板载"那张表里的管脚。
- 输入脚不能写 `DRIVESTRENGTH`（TD 会报错）；步进 UART 的发送脚默认上拉（空闲为高）。

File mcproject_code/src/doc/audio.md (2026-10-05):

# 音频：TF 卡 WAV → ES8388 → 喇叭口（背景音乐 + 音效，两路同时播）

状态：RTL 全部有测试台并仿真通过（§8）；**没有上板**。真实 TF 卡的兼容性、ES8388 模拟输出、功放、爆音、重采样的音质只能上板确认。

## 1. 三段音频怎么分工

| 文件 | 用途 | 谁触发 | 播几遍 |
| --- | --- | --- | --- |
| `1.wav` | 背景音乐 | 上电后 TF 卡和 ES8388 都准备好就**自动开始**（没有开关） | 无限循环 |
| `2.wav` | 进食音效 | 霍尔传感器 = 1（`app/mc_behavior.v`） | 每次磁铁靠近播一遍；播放中不会被重复触发，磁铁不拿开也不重播 |
| `3.wav` | 狗叫 | **以后** UWB 检测不到 / 太远时给 `mc_behavior` 的 `I_bark`；现在 `I_bark` 接 0，没人触发 | 条件一直成立就循环叫 |

**两个喇叭口分开放**：ES8388 的左、右声道是两个独立的 DAC，分别经功放到 J12（左）和 J11（右）。**J12 = 背景音乐，J11 = 音效**，各响各的（**两个口各接一个喇叭**），音效不打断背景音乐，音效放完背景音乐也不用"恢复"（它一直在放）。要做到这点必须同时读两个文件，所以有两个读文件模块共用一份挂载 + 目录表（`mc_fat32`）和一个 SD 控制器，由 `mc_sd_arb` 轮流给。

## 2. 架构和文件（`src/rtl/audio/`）

```
                                    ┌ 读文件 #0 ─ mc_wav_player #0 ─┐（背景音乐：1.wav，循环）
 TF 卡 ─ mc_sd_spi ─ mc_sd_arb ─ mc_fat32                          ├─ mc_audio_mix ─ mc_i2s_tx ─► ES8388 ─► J12 左 / J11 右 / 耳机口 J3
 (SPI)   读扇区      轮流给      │（挂载 + 目录表 一份）            │                                 ▲ I2C 配置：mc_es8388_cfg + mc_i2c_wr
                                    └ 读文件 #1 ─ mc_wav_player #1 ─┘（音效：一次一遍）
```
全部在 100 MHz 时钟域（MCLK 也是它分出来的），没有跨时钟域。`mc_audio.v` 把它们连成一个模块，顶层只例化它。

| 文件 | 作用 |
| --- | --- |
| `mc_audio.v` | 顶层封装：命令口 + 状态口 + 引脚；背景音乐的"准备好就自动播"逻辑 |
| `mc_sd_arb.v` | 两路读文件共用一个 SD 控制器：一次读扇区不被打断；两边同时要就轮流（谁刚用过谁排后面）；请求会被记住（每方挂 1 个）；数据 / done / err 只送给提出这次请求的那一方 |
| `mc_wav_player.v` | WAV 播放器：向读文件模块要文件字节 → 解析 RIFF / fmt / data（其他块跳过）→ 一帧一帧交给混音器；2 KB 环形缓冲；错误码 |
| `mc_audio_mix.v` | 两路各自重采样到 I2S 帧率（§6）+ 背景音乐放左声道、音效放右声道（立体声文件先左右取平均） |
| `mc_fat32.v` | 最小 FAT32 读取器的外壳：一个 `mc_fat_dir` + 两个 `mc_fat_rd`。挂载期间 0 号读扇区口给 `mc_fat_dir`，挂载完成后归 0 路读文件 |
| `mc_fat_dir.v` | 挂载（带 / 不带 MBR）+ 扫描根目录找 `数字.WAV` + 目录表（编号 → 文件大小和起始簇，64 项，每路读文件各读一份内容相同的 RAM，不用排队）。**两路共用，上电只扫一遍** |
| `mc_fat_rd.v` | 读一个文件：按目录表找到起始簇，沿 FAT 簇链一个扇区一个扇区地读，把文件内容一个字节一个字节地送出；缓冲没空位就等；可以中途关闭。背景音乐、音效各一个 |
| `mc_sd_spi.v` | TF 卡 SPI 模式：上电初始化（区分 V1 / V2、SDSC / SDHC）+ 读 512 字节扇区。初始化 390 kHz，之后 12.5 MHz |
| `mc_i2s_tx.v` | I2S 发送 + MCLK / SCLK / LRCK：MCLK = 100 MHz ÷ 8 = 12.5 MHz；LRCK 固定 ÷ 256 = **48828.125 Hz**（比值不变，换曲目不会出杂音） |
| `mc_es8388_cfg.v` + `mc_i2c_wr.v` | 上电后把 ES8388 配成"I2S 从模式、16 位、DAC 播放"（§7）。I2C 地址 0x11，100 kHz |

## 3. 接线和板上资源

**ES8388**（板载，不用接线；引脚已写进 `mc_pin.adc`）：

| 信号 | FPGA 脚 | 说明 |
| --- | --- | --- |
| `O_aud_mclk` | F14 | MCLK 12.5 MHz（原理图上 12.288 MHz 晶振 X4 标 NC，MCLK 由 FPGA 经 `R185` 给，和厂商例程一样） |
| `O_aud_sclk` / `O_aud_lrck` / `O_aud_dsdin` | K13 / C13 / J13 | I2S 位时钟 / 左右声道时钟 / FPGA → DAC 数据 |
| `O_aud_cclk` / `IO_aud_cdata` | A13 / B14 | I2C SCL / SDA（板上有上拉）。CE（A12）板上上拉 → 地址 0x11，**不要驱动**它 |
| `O_spk_ctl` | K15 | 喇叭功放使能（高有效，这里恒为 1） |

**喇叭口怎么接**（读底板原理图 P05_AUDIO 页；硬件手册写"扬声器接口为 NC 状态"，我理解成出厂没接喇叭）：

- ES8388 的 LOUT2 / ROUT2 各进一颗 **TT8642 单声道 D 类功放**（`U41` / `U40`，EN 脚接 `SPK_CTL_H`），输出到两个 **2 针排针：`J12` = 左声道、`J11` = 右声道**，间距 2.54 mm。
- **一个喇叭 = 两根线，接在同一个口的两个针上。** 两个口各接一个喇叭 = 背景音乐和音效分开放。
- 功放是 BTL 差分输出：**喇叭的两根线都不能接地**（接地会没声音甚至损坏功放）。
- 硬件参数图上圈出的 L22 / L23 / L25 / L26 **不是引脚，是功放输出端的磁珠**（L22/L23 属于 U41 → J12，L25/L26 属于 U40 → J11）。
- 如果板子上 J11 / J12 没焊排针，直接把喇叭线焊到焊盘上。TT8642 的功率没查到数据手册：先用 4~8 Ω 小喇叭。音量已经开到最大（`AUD_SPK_VOL = 33`，+4.5 dB）：响度够、但音乐本身很响（接近满幅）时可能破音，破音就把它改回 30（0 dB）。
- 耳机口 `J3` 直接出声，不需要功放（和喇叭口同一路信号：背景音乐在左耳、音效在右耳）。

**TF 卡座**（SPI 模式用 4 根线，3.3 V）：`O_sd_cs_n` E5（DAT3）、`O_sd_sck` D9（CLK）、`O_sd_mosi` C9（CMD）、`I_sd_miso` E6（DAT0）；E7 D5 D8 不用。

## 4. TF 卡和 WAV 文件

| 项 | 内容 |
| --- | --- |
| 放在哪 | **TF 卡根目录**（不要放子文件夹） |
| 文件名 | 数字 + `.wav`：`1.wav` … `64.wav`（`01.wav` 也算第 1 个）。其他名字被忽略。最多 64 个（`mc_fat_dir.v` / `mc_fat_rd.v` 里的 `N_CLIPS`） |
| 卡的格式 | **FAT32**（≤ 32 GB 的卡出厂默认就是；64 GB 以上默认 exFAT，不支持，要格式化成 FAT32）。带不带分区表都行 |
| WAV 格式 | **16 位 PCM**，单声道或立体声，采样率 **8000 ~ 48828 Hz**（超出会报"格式不支持"）。背景音乐**强烈建议 48 kHz**（§6）；音效、狗叫随便（16 kHz 单声道就够） |
| 传文件 | 断电 → TF 卡插读卡器 → 拷进根目录 → 弹出 → 插进板子 → 上电。**不支持热插拔**：插好卡再上电（或 SW1 按住 2 秒整机复位） |
| 格式转换 | 背景音乐：`ffmpeg -i 输入.mp3 -ar 48000 -ac 2 -c:a pcm_s16le 1.wav`；进食音效 / 狗叫：`ffmpeg -i 输入.mp3 -ar 16000 -ac 1 -c:a pcm_s16le 2.wav`（改文件名 3.wav 同理）。Audacity：导出 → WAV → "Signed 16-bit PCM" |
| 实际速度 | I2S 帧率是 48828.125 Hz，比标准 48 kHz 高 1.7 %：48 kHz 的文件实际快 1.7 %（听不出来）；其他采样率按精确比例重采样，速度准确 |

## 5. 怎么用

**没有按键操作**（2026-10-05 删掉了台架的音频页：规则已经定好，不用在板上调）：背景音乐上电自动循环，进食音效由霍尔触发，狗叫以后由 UWB 触发。

屏幕中间状态带第 1 行显示音频状态：`SD`（INIT / READY / NO SD / NO FAT）、`CODEC`（INIT / OK / ERR）、`BGM` / `SFX`（IDLE / OPEN / PLAY / ERR）。

**`mc_audio` 的端口**（Verilog 里没有"函数调用"：给输入端口一个命令，读输出端口）：

| 端口 | 方向 | 含义 |
| --- | --- | --- |
| `I_sfx_play` + `I_sfx_clip[6:0]` | 入 | 单周期脉冲：播 `<I_sfx_clip>.wav` 一遍。**音效正在播时收到的播放命令被忽略**（不重复触发、不打断） |
| `O_ready` | 出 | TF 卡已挂载 + ES8388 已配置好 |
| `O_sd_state` / `O_codec_state` / `O_nclips` | 出 | TF 卡 0 初始化中 1 就绪 2 没卡 3 不是 FAT32；ES8388 0 配置中 1 正常 2 I2C 无应答；找到几个 N.wav |
| `O_bgm_state` / `O_sfx_state` | 出 | 0 空闲 1 打开中 2 播放中 3 出错 |
| `O_bgm_err` / `O_sfx_err` | 出 | 1 没有这个编号的文件 2 不是 WAV 3 格式不支持（含采样率 > 48828 Hz） 4 读卡错误 5 TF 卡没准备好 |
| `O_sfx_busy` / `O_sfx_cur` | 出 | 音效正在打开 / 播放；正在播的曲目号 |
| `O_bgm_ur` / `O_sfx_ur` | 出 | 这一路数据没跟上的次数（上板应一直是 0） |

`mctop.v` 配置区：`AUD_BGM_CLIP`（1）、`AUD_EAT_CLIP`（2）、`AUD_BARK_CLIP`（3）、音量 `AUD_HP_VOL`（耳机）/ `AUD_SPK_VOL`（喇叭），0~33，30 = 0 dB，每级 1.5 dB，**两个都是 33（最大）**——音量是上电时写进 ES8388 的一个寄存器值，开多大都不占逻辑资源。背景音乐在左（J12）、音效在右（J11）是固定的，没有混合 / 衰减选项。

**没有屏幕时怎么知道音频好了：** 听。上电后（TF 卡初始化 + ES8388 配置，通常 1 秒左右，卡慢的话几秒）J12 / 左耳应该开始放 1.wav，到头自动再放。没声音就按 §9 排查；LED 不显示音频状态。

## 6. 重采样和混音（`mc_audio_mix.v`）

- LRCK 固定 48828.125 Hz。每一路按"自己的采样率 ÷ 48828.125"决定每个 I2S 帧要不要取新的一帧，不取就重复上一帧（**零阶保持**）。相位累加器的单位是 1/8 Hz，整数运算。
- **≥ 47.5 kHz 一律当原生 48 kHz**：每帧取一次，不重采样，音质最好。其他采样率（44.1 / 32 / 24 / 16 / 12 / 8 kHz）速度准确，但高频有点"毛"（零阶保持的镜像）。所以**背景音乐转成 48 kHz**，音效随便。想再好一点可以改线性插值（以后的事）。
- 一路刚开始播的那个 I2S 帧就取第一个采样（和上一个文件的采样率无关）；播放器没准备好（欠载）这一帧这一路补静音并给 `O_ur` 一个脉冲；不在播的那一路送静音。
- 左声道 = 背景音乐，右声道 = 音效；立体声文件先左右取平均（`(L + R) >> 1`）变成单声道。
- 背景音乐循环：文件播完立刻重新打开，衔接处有一个很短的停顿（毫秒级）。
- WAV 头解析：`RIFF` → 总长（跳过）→ `WAVE` → 依次读块：`fmt ` 取格式（必须 PCM、16 位、声道 1 或 2、采样率 8000~48828）；`data` 开始播放，长度以 data 块为准；其他块（`LIST`、`fact`）整块跳过。缓冲 2 KB，`mc_fat_rd` 有 ≥ 512 字节空位才读下一个扇区。

## 7. ES8388 配置顺序（`mc_es8388_cfg.v`）

| # | 寄存器 = 值 | 意义 |
| --- | --- | --- |
| 0 | R0 = 0x80 | 软复位 |
| 1 | R0 = 0x00，等 20 ms | 复位结束 |
| 2~3 | R1 = 0x58 → 0x50 | 模拟电源先低功耗上电，再整体打开 |
| 4~5 | R2 = 0xF3 → 0x00 | 数字部分先复位着，再放开 |
| 6 | R3 = 0xFF | ADC 全部断电（只播放） |
| 7 | R0 = 0x06 | 使能参考，VMID 500 kΩ 分压 |
| 8 | R4 = 0x3C | 左右 DAC 上电，LOUT1/ROUT1/LOUT2/ROUT2 全部使能 |
| 9 | R8 = 0x00 | 从模式，MCLK 不分频 |
| 10 | R23 = 0x18 | DAC：I2S 格式，16 位 |
| 11 | R24 = 0x02 | DAC：单倍速，比值 256 |
| 12~13 | R26 / R27 = 0x00 | 左右 DAC 数字音量 0 dB |
| 14~15 | R39 / R42 = 0x90 | 左右混频器：只放 DAC |
| 16 | R43 = 0x80 | DAC 与 ADC 共用 LRCK |
| 17~18 | R46 / R47 = `HP_VOL` | 耳机左右音量 |
| 19~20 | R48 / R49 = `SPK_VOL` | 喇叭左右音量（经板上功放） |

顺序和数值取自厂商例程 `09_aud8388_loop`，寄存器含义对过 ES8388 数据手册。

## 8. 仿真验证（`bash tools/sim.sh <名字>`；每个都做过突变检查）

| 测试台 | 覆盖 |
| --- | --- |
| `tb_i2s` | 标准 I2S 接收器解出的每一帧 = 送进去的；缺数据发静音 + `O_underrun`；MCLK 周期；SCLK / LRCK 比值 |
| `tb_es8388` | I2C 波形、21 条寄存器写入的号码 / 数值 / 顺序；不应答时报错并停止 |
| `tb_sdfat` | 行为级 SD 卡（V2 大容量 / V1 字节寻址）：初始化、带 MBR 和不带分区表（两种跳转指令 EB / E9；引导代码区填了非零杂数，检查字段只在该取的位置取）、根目录扫描——**诱饵项**：卷标 / 长文件名 / 子目录 / 已删除 / 非数字名 / 扩展名不是 WAV（每个字符各错一次）/ 编号 0 和 65 / 99 / 数字名的"卷标" / 起始簇 0 的空文件 / 4 位数字（1025 绕回成 1）/ 名字第 8 个字符不是空格 / 同一首的重复目录项（只算一首）；5.wav 在目录第 2 个簇；**目录刚好填满簇、靠簇链结尾标记（0x0FFFFFF8）结束**；只有 1 份 FAT；`64.WAV`（最大编号）能打开读对；**挂载一共读了多少个扇区**（按镜像目录结构数出来的精确值：不能多扫）；逐字节核对文件内容（碎片化簇链，簇号落在 FAT 的第 1、2 个扇区；4.wav 目录大小 ≥ 16 MB + 64 KB，簇链用最小结尾标记）、打开不存在 / 越界的编号、中途关闭、**打开后 1~6 个时钟就关闭（落在查目录表的几拍里，关闭不能丢）**、没插卡（挂载码 4）/ 全零的卡；**挂载失败的各个出口**：引导扇区签名第 1 / 第 2 字节坏（无分区表 / 分区的引导扇区 / MBR）、每扇区字节数不是 512、FAT 大小为 0、3 份 FAT、每簇 3 个扇区、根目录起始簇 1；**读卡错误**（卡在第 N 次读扇区时报错）：挂载期间第 0 扇区 / 分区引导扇区 / 根目录扇区 / 目录的 FAT 查询 → 挂载失败码 4，挂载完成后数据扇区 / 打开碎片化文件时的 FAT 查询 → 打开失败码 4 且之后还能正常打开；白盒：读文件模块只在缓冲有空位时才读下一个数据扇区；`S_spc_ok` 和 `log2` 查表对 0~255 逐值核对 |
| `tb_sdarb` | 一个真 `mc_fat32`（挂载 + 目录表一份，两路读文件）+ 真 `mc_sd_arb` + 真 `mc_sd_spi`（行为级 SD 卡）：挂载只扫一遍、同时读不同文件逐字节核对（缓冲忙闲随机，含两路读同一个文件）、反复交替打开、**任意一路**中途关闭另一路不受影响、**任意一路**打开不存在的编号只有这一路报错、两路同时打开不存在的编号都报错（两路各查各的目录表） |
| `tb_sdarb_proto` | 仲裁器接口约定（协议级，脚本化的 SD 卡一侧）：数据 / done / err 只给主人且同拍、`O_busy` 精确、`O_start` 一拍宽且 SD 不忙时才发、同一拍两方请求的先后（两个方向）、传输中来的请求被记住、两方连续抢严格交替、读出错只有主人收到 err 且仲裁器恢复、传输中复位挂起的请求清掉 |
| `tb_audio_mix` | 混音器：两路空闲静音、一路先开始另一路中途加入、48 kHz 每帧恰好取一次、16 / 44.1 / 12 kHz 取样个数和用掉的帧数精确、**47500 Hz 起当作原生 48 kHz 的边界（47500 / 47499）**、**8000 / 4000 Hz 相位累加恰好等于一帧的那一帧（每 3125 帧一次）**、左 = 背景音乐、右 = 音效（含正负极值）、欠载补静音 + `O_ur`（**两路各测**）、"打开中"碰上帧节拍不算在播；参考模型在测试台里独立写了一遍，逐帧核对输出 |
| `tb_audio` | 错误 1 / 2 / 3（不存在 / 头不对 / 96 kHz）且不影响背景音乐、之后还能正常播；LRCK 周期；**白盒接线核对**：挂载 + 目录表、两路读文件、仲裁器、SD 控制器、播放器、混音器、I2S 之间每根线是否各接各的（比如音效那一路的"缓冲有空位"是不是接自己的播放器：背景音乐文件很短时它恒为 1，功能测试看不出来；两路各读自己的目录表读口；所有连线**每个时钟**都核对，一次性的单周期脉冲——打开 / 关闭 / 曲目号 / 读扇区命令 / 打开失败 / 文件结束 / 取走一帧 / 帧节拍——也不会漏；仿真里 SD 卡从不出错，两个口的"读错误"一直是 0，接反看不出来，所以另外用 `force` 把仲裁器两个口的读错误强制成不同的值，核对目录模块 / 两路读文件模块各收到自己那一路的；混音器给两个播放器的"欠载"标志同理：两路都在播的时候各来一个时钟，核对各播放器的欠载计数只数自己那一路；复位一松开就开始核对，所以"SD 就绪 / 已挂载"这类接常数的错在 0 时刻就被抓到） |
| `tb_top` | 顶层接线：音量参数 = 33；背景音乐上电自动开始，**第一个采样 = 1.wav 第 0 个采样**，右声道没触发时静音；喂食（霍尔 = 1）播的是 2 号、一次一遍（第一个采样核对）；行为层 → 音频的命令线每个时钟白盒核对；SW1 按住 2 秒复位后背景音乐自己再开始 |

**仿真不了的**：真实 TF 卡的兼容性（有的卡初始化慢、SPI 速度上限不同）、ES8388 的模拟输出和板上功放、上电爆音、喇叭是否破音、重采样（零阶保持）的音质。
**测试没覆盖的**：采样率低于 8 kHz 的文件（播放器的下限判断；上限用 96 kHz 的 8.wav 测了）；上电时磁铁就在旁边、而音频还没准备好的情况（`mc_behavior` 会等到准备好再播，这条逻辑有单元测试，顶层没单独测）；音频子系统里真实发生的**欠载**（仿真里数据总跟得上，欠载标志的接线靠 `force` 核对，欠载本身的计数靠 `tb_audio_mix` 的补静音 + `O_ur` 覆盖）。

## 9. 排错

| 现象 | 先怀疑 | 怎么查 |
| --- | --- | --- |
| `CODEC ERR` | ES8388 的 I2C 没应答 | `A13` / `B14` 是否接对、板上 R191 / R172 是否在；ChipWatcher 抓 `O_aud_cclk` / `IO_aud_cdata` |
| `CODEC OK`、`BGM PLAY` 但没声音 | 功放没使能 / 喇叭线接法 | `O_spk_ctl`（K15）是否为高；喇叭两根线接在 J11 或 J12 的两个针上、不接地；先接耳机口听 |
| 有声音，但噪声大 / 音调不对 | MCLK 太差 / 比值 | 示波器看 F14 是否 12.5 MHz、K13（3.125 MHz）和 C13（48.8 kHz）是否稳定 |
| 背景音乐不响，别的都正常 | TF 卡 / 文件 | `SD` 是不是 READY、`BGM` 是不是 ERR；根目录有没有 `1.wav` |
| `SD NO SD` | 没插卡 / 卡座接触 / SPI 脚 | 插好卡后 SW1 按住 2 秒复位；E5 / D9 / C9 / E6 是否对；换卡（有的卡对 SPI 模式支持差） |
| `SD NO FAT` | 卡不是 FAT32 | 重新格式化成 FAT32 |
| `SD READY` 但 `BGM ERR` | 文件名不对 / 不在根目录 / 格式不对 | 必须是 `1.wav` 这样的数字名；Windows"隐藏已知文件类型"开着时别写成 `1.wav.wav` |
| 声音断续 | 卡太慢 | 换 Class 10 的卡；把 `mc_sd_spi.v` 的 `FAST_DIV` 改小（4 → 3 提到 16.7 MHz，不稳就改回） |
| 背景音乐有点"毛" | 不是 48 kHz | 转成 48 kHz（§4） |

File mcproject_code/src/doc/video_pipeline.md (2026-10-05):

# 视频通路说明：摄像头 → 屏幕（竖屏）

IMX415 ─MIPI CSI 4lane─► 取窗 ─► ISP ─► DDR2 帧缓存 ─► MIPI DSI 4lane ─► 10.1" 800×1280 屏。
状态：2026-10-05 第一次接屏上板，画面是**竖条纹（像条形码）、文字和状态方块被压扁 / 出现两层、整屏不停抖、偶尔全黑**。已按 §6 第一行改（水平消隐照抄厂商例程）+ 白平衡改成逐帧算（§9），仿真通过、TD 完整流程通过，**还没再上板**。
按键、文字区、尾巴、霍尔见 [`hmi_tail.md`](hmi_tail.md)；音频见 [`audio.md`](audio.md)；它们和视频通路互不依赖，只是文字层挂在 `mc_mixer` 里。

---

## 1. 架构

```
 CSI 口 ◄── IMX415                                                          DSI 口 ──► 10.1" 屏
   │ I2C / INCK / RST                                                        ▲ MIPI 4lane    ▲ 背光 / 复位
   ▼                                                                         │               │
┌─────── mc_cam_if 摄像头接口（时钟 = MIPI RX 字节时钟 111.4 MHz）─────────┐ ┌──── mc_disp_if 显示接口（时钟 = DSI 字节时钟 68.49 MHz）────┐
│ mc_cam_pwrup → uicfgimx415(I2C) ◄ ae_set(SW2/SW3 短按调增益)            │ │ mc_panel_ctrl → display_config_wrapper(ROM: ILI9881C 初始化)  │
│ D-PHY RX → csi_unpacket_4lane → raw10_unpacket_4lane → mc_crop(取窗)     │ │ video_tpg(时序) → mc_mixer(画布版面：相机窗口/状态方块/文字层)│
│        → isp_top(去马赛克 + 白平衡) → 128bit 打包 RGB 像素流             │ │ → rgb_24b_to_32b → dsi_video_mode_packet → D-PHY TX          │
└────────────────────────────┬─────────────────────────────────────────────┘ └──────────▲──────────────────────────▲───────────────────────┘
                             │ 像素流                                                   读使能 / 像素 │
                             ▼                                                                       │
                     ┌─────────── mc_framebuf 帧缓存（时钟 = DDR 用户时钟 132.8 MHz）─────────────────┴──┐
                     │ video_in ─► mc_to_user_interface ─► DDR2 控制器 ◄── video_out（厂商，顺序读）      │
                     │ （写入：4 缓冲轮换）                                                                │
                     └────────────────────────────────────────────────────────────────────────────────────┘
mctop：PLL（100 / 24 / 52.17 / 10 MHz）· 复位同步 · mc_tick · 状态汇总 → LED + 画面上的 8 个状态方块
```

三个块之间只传"像素流"和少量状态位；跨时钟域都用同步器或异步 FIFO。**以后加避障：在 `mc_cam_if` 的像素流上并联分析模块，在 `mc_mixer` 里把处理结果 + 框画到屏幕下半部分。**

## 2. 文件清单

来源列：**自写** = 本项目新写；**原样** = 厂商文件一字未改；**改** = 厂商文件改过（见 §9）。`*.enc.v` 是加密模块，看不到源码。

| 路径（相对 `src/rtl/`） | 作用 | 来源 |
| --- | --- | --- |
| `mctop.v` | 顶层：端口、PLL、复位、节拍、视频三个块的连线、状态汇总、LED，以及按键 / 尾巴 / 霍尔 / 行为层 / 文字面板 / 音频的例化。**配置区**（排线极性、取窗、屏幕版面、尾巴、霍尔、音频）在文件前部 | 自写 |
| `system/mc_rst_sync.v` `mc_tick.v` `mc_sync_bits.v` `mc_activity_mon.v` | 复位同步器；节拍脉冲；两级同步器；"最近 100 ms 内有没有帧"监测 | 自写 |
| `video/cam/mc_cam_if.v` | **摄像头接口**：把下面这些模块串起来，输出像素流 | 自写 |
| `video/cam/mc_cam_pwrup.v` | 传感器上电时序：INCK 稳定 → 10 ms 后释放复位 → 40 ms 后才允许 I2C 配置 | 自写 |
| `video/cam/uicfgimx415.v` `uii2c.v` `uiimx415reg.v` | IMX415 的 I2C 配置：201 条寄存器（1080p、4-lane、891 Mbps、INCK 24 MHz） | 原样（IMX415 例程） |
| `video/cam/ae_set.v` `key.v` | 手动调增益：增益值 `O_ae`（初值 50）每个低电平脉冲（≥ 30 ms）±1 级，改完经 I2C 写进传感器。脉冲由 `mc_bench`（SW2/SW3 短按）给 | 原样（IMX415 例程） |
| `video/rx/mipi_dphy_rx/*`（7 个） | MIPI D-PHY RX 硬核封装 + 字节对齐 + 通道对齐 | 原样（例程 08） |
| `video/rx/csi_unpacket_4lane.v` `raw10_unpacket_4lane.v` | 解析 CSI-2 包头；RAW10 解包成每拍 4 个像素 | 原样（IMX415 例程） |
| `video/isp/mc_crop.v` | 取窗：从 1920×1080 里截 800×560 | 自写 |
| `video/isp/isp_top.v` | ISP 顶层：去马赛克 → 白平衡 → 打包成 128bit | 改（参数化） |
| `video/isp/awb.v` | **自动白平衡**：一帧里累加 R / G / B，帧开始时用一个移位相减的除法器算一次 G/R、G/B 增益，平滑后下一帧整帧使用 | **改（重写增益计算，§9）** |
| `video/isp/demosaic/*` `signal_delay.v` `data96_128/` `data128_96/` | 双线性去马赛克（3×3 窗）、白平衡的数据延迟线、位宽转换 | 原样（例程 08） |
| `video/fb/mc_framebuf.v` | **帧缓存**：连接 video_in / video_out / DDR 控制器 | 自写（连线照搬例程 08） |
| `video/fb/video_in.v` `video_out.v` `mc_to_user_interface.v` `ph1p35_324_ddr_wrapper.v` | 写 DDR（4 缓冲轮换）、读 DDR（顺序读）、用户口 → 控制器、DDR2 控制器封装 | 原样（例程 08） |
| `video/disp/mc_disp_if.v` | **显示接口**：面板时序参数、DSI 打包、D-PHY TX | 自写（连线照搬例程 08） |
| `video/disp/mc_panel_ctrl.v` | 面板上电时序：复位 20 ms → 等 150 ms → 发初始化脚本 → 完成后开背光 | 自写 |
| `video/disp/mc_mixer.v` | 画面合成：**版面**（相机窗口、状态方块、文字层）；没有相机帧时窗口是黑色；红蓝互换。流水线 6 拍 | 自写 |
| `video/disp/video_tpg.v` | 视频时序发生器 + 背景测试图案（`BG_PATTERN=1` 时才显示） | 原样（例程 08） |
| `video/disp/dsi_tx_packet/*` | 初始化脚本解释器（ROM → LP 命令）、RGB 打包、DSI 视频包、ECC/CRC（加密） | 原样（例程 08） |
| `video/disp/mipi_dphy_tx/*` | MIPI D-PHY TX 硬核封装 + DPLL | 原样（例程 08） |
| `video/disp/panel/ili9881c_k101_init.txt` | **屏幕初始化脚本源文件**（可读、可改） | 自写（数值取自 Linux 内核） |
| `video/disp/panel/make_rom.ps1` | 把上面的文本转成 ROM IP 的 `.mif` / `.mif.dat` | 自写 |

IP（`src/ip/`）：`mcsys_pll`、`ddr2`、`w128_d512_fifo`、`w155_d512_fifo`、`w32_d512_fifo` `w8_d1024_fifo`（加密的 DSI 打包核里用）、`w8_d1024_rom`（面板初始化 ROM）、`blk_mem_gen_*`（去马赛克 / 白平衡延迟线的 RAM）。原来白平衡用的 `divider` IP 已删掉。
约束：`src/pin/mc_pin.adc`（管脚）、`src/pin/mc_timing.sdc`（时钟）；DDR2 的管脚和时序约束在 `ip/ddr2/src/{adc,sdc}/`，TD 会自动带上。

## 3. 接线

| 底板连接器 | 接什么 | 排线 |
| --- | --- | --- |
| **CSI**（底板下沿左边那个，丝印 `CSI`） | CAM002 摄像头 | CAM002 随附的 40P 排线 |
| **DSI**（底板下沿右边那个，丝印 `DSI`） | 10.1" 屏 | 屏幕软排线：**标 `MLK` 的一端接底板 DSI 座，标 `LCM` 的一端接屏幕的 40P 座** |

- 断电后插拔；两个座都是后掀式：掀起锁扣 → 排线插到底 → 压回锁扣。参照厂商教程第 78 页照片：CSI 排线蓝色加强片朝上；DSI 排线印 `MLK` / `PCBA` 的一面朝上，`1` 号脚标记在右端。
- 屏幕资料图里的 40pin 定义和底板 DSI 座逐脚一致（直通排线）。
- 供电：5V/3A 以上的稳压适配器接 Type-C。**不要热插拔 JTAG。**

## 4. 屏幕版面（只做竖屏 800 宽 × 1280 高）

坐标 (u, v)：u 向右、v 向下，单位像素。**上半相机、中间状态带、下半留给避障**：

| 区域 | 坐标 | 做什么 |
| --- | --- | --- |
| **相机窗口** | u 0~799，v 0~559（800×560） | 传感器正中 800×560 的裁切（约整幅画面的 42%×52%，**不拉伸、不缩放**）。没有相机帧时是黑色 |
| **状态方块** | v 568~607，u = 40 + 90k（k = 0~7），每个 80×40 | 绿 = 1 / 红 = 0，从左到右：`[0]` 心跳（每秒红绿交替）｜`[1]` DDR2 校准完成｜`[2]` 屏幕初始化脚本发完｜`[3]` 相机寄存器配完｜`[4]` 收到 MIPI 帧｜`[5]` ISP 帧进入帧缓存｜`[6]` 无 MIPI 通道错误｜`[7]` 常绿（红绿色序参考） |
| **文字区** | u 40~759，v 616~711（45 列 × 3 行，每字符 16×32） | 黑底白字：增益 / 霍尔 / 尾巴 / 按键 / 开机秒数、音频状态、按键提示（`hmi_tail.md` §4） |
| **下半** | v 720~1279（800×560，和相机窗口一样大） | **黑色，留给避障**：以后放"处理后的画面 + 画框" |

```
v = 0    ┌────────────────────────────┐
         │ 相机窗口 800×560           │
v = 559  ├────────────────────────────┤
v = 568  │ ■ ■ ■ ■ ■ ■ ■ ■  (80×40)   │  状态带
v = 616  │ GAIN 050  HALL 0  TAIL ... │  3 行文字
v = 711  │ ...                         │
v = 720  ├────────────────────────────┤
         │ 黑（800×560，留给避障）     │
v = 1279 └────────────────────────────┘
```

叠放顺序（从上到下）：文字层 > 相机窗口 > 状态方块 > 背景（`tb_mixer` 用重叠版面核对过）。版面参数只在 `mctop.v` 配置区改。

## 5. 上板步骤与预期现象

1. TD 里 Generate Bitstream → 下载（也可以直接下载 `src/boot/MinecraftDog_FPGA.bit`）。
2. LED1 约 1 Hz 闪。约 0.3 s 后屏幕背光亮，出现状态方块和文字（相机没接也会出现）；LED2 常亮。
3. 接了相机：LED3 常亮，屏幕上半部分出现**稳定**的实时画面；方块 `[3] [4] [5] [6]` 绿。
4. 曝光不合适：SW2 短按增益 +1、SW3 短按增益 -1（文字第 0 行 `GAIN`）。
5. 白平衡：上电后几帧内颜色逐渐变正（增益每帧走剩余差距的 1/4，十几帧收敛）。
6. **想先只验证屏幕链路**（不看相机）：`mctop.v` 的 `BG_PATTERN` 改 1，没内容的地方会显示测试图案（马赛克）。

## 6. 排错

| 现象 | 先怀疑 | 怎么查 / 改 |
| --- | --- | --- |
| **竖条纹（像条形码）、字和方块被压扁 / 两层、整屏抖、偶尔全黑**（2026-10-05 上板现象） | ① DSI 包撞在一起（水平消隐不够）；② 初始化脚本和这块屏不匹配 | ① 已改：水平消隐照抄厂商例程 24/136/160（`mc_disp_if.v`）。② 还是这样：向商家（米联客）要**这块 10.1" 屏（ILI9881C，触摸板丝印 CC10128007-31C）的 MIPI 初始化代码**，按 `panel/ili9881c_k101_init.txt` 的格式（`PAGE` / `REG` / `CMD` / `DELAY`）抄进去，运行 `make_rom.ps1`，重新生成 bit。看图案判断：`BG_PATTERN = 1` 时马赛克能正常显示 → 屏幕链路好了，问题在相机侧 |
| 屏幕一直全黑，LED1 闪 | 屏幕初始化没生效 / 排线 / 供电 | 断电重插排线；LED2 是否亮；换稳压电源；初始化脚本（上一行） |
| LED2 一直灭 | DDR2 没校准成功 | 重新下载；检查是不是改过 `ddr2` IP 或管脚约束 |
| LED2 一直闪 | 面板脚本没发完，通常是 MIPI TX 的 DPLL 没锁 | `mc_disp_if.v` 的 `DPLL_MULTI_RATIO`；PLL clk2 是否 52.17 MHz |
| 屏幕好了，但相机窗口里是竖条纹 / 花的 | 相机侧（MIPI 收、ISP、帧缓存） | 看方块 `[4] [5] [6]`：`[4]` 红 = 没收到 MIPI 帧（排线、`CAM_LANE_INVERT`）；`[6]` 红 = 通道错误；都绿还花 → ChipWatcher 抓 `u_cam/u_crop` 的输出 |
| 红蓝反了 | 色序 | `mctop.v` 的 `RB_SWAP` 改 1 |
| 图案左右镜像 | 扫描方向 | 脚本 PAGE 1 的 `REG 22`（SS 位），改完运行 `make_rom.ps1` |
| 方块 `[3]` 红 | 相机 I2C 没配完 | 摄像头排线、V9 的 24 MHz、相机供电 |
| `[3]` 绿 `[4]` 红 | 没收到 MIPI 帧 | 排线；`CAM_LANE_INVERT` 逐位试；看 `[6]` |
| `[4]` 绿 `[5]` 红 | 有 CSI 帧但取窗后没有输出 | 取窗参数和传感器实际输出尺寸对不上：`CROP_X0_GRP` / `CROP_Y0` |
| 图像有，但整体发绿/发暗/过曝 | 白平衡还没收敛 / 曝光 | 等几帧；SW2 / SW3 调增益 |
| 图像呈网格状、颜色怪 | Bayer 相位 | `CROP_Y0` 必须是奇数；`mc_cam_if.v` 里 `isp_top` 的 `BAYER_MODE` |

## 7. 显示时序（为什么是这几个数）

- DSI 字节时钟 = 52.17 MHz × (`DPLL_MULTI_RATIO` + 1) / 16 = **68.49 MHz**（TD 时序报告里推出来的值，和厂商 7 寸屏例程一样），每通道 548 Mbps。整条显示流水线跑在这个时钟上，1 个时钟 = 1 个像素。
- **水平**：有效 800 + HSA 24 + HBP 136 + HFP 160 = 1120。**消隐和厂商例程一字不差**：加密的 DSI 打包核不看 D-PHY 的 `ready`（`APUG042` 图 2-5：一个高速包发完，`ready` 要拉低到回到 LP 才能发下一个），只靠消隐时间留出空隙。以前给的 24/100/76（共 200 个时钟，比厂商少 120 个）上板就出了 §6 第一行的现象。**不要再压缩水平消隐。**
- **垂直**：有效 1280 + VSA 6 + VBP 15 + VFP 16 = 1317（ILI9881C 10.1" 面板的典型值，Linux 内核 K101-IM2BYL02）。
- 刷新率 = 68.49 MHz / (1120 × 1317) ≈ **46.4 Hz**。相机 60 帧，显示端读"往前数第 2 帧"（4 缓冲），不撕裂。画面稳定以后想要 60 Hz：把 `DPLL_MULTI_RATIO` 改成 26（88.0 MHz、每通道 704 Mbps，≈ 59.7 Hz），时序余量够（显示时钟域现在能跑到 170 MHz 以上），但这会改变 DSI 速率，要上板确认。
- 初始化脚本的 ROM 格式已用厂商资料核对：`01 长度 数据…` = DCS 长包（厂商另一个屏的 ROM `config_data_nes.mif` 就是这样写的）、`02 寄存器 值`、`03 命令`、`04` + 4 字节延时（10 MHz 计数）、`05` 结束。

## 8. 约束：IO 约束和时序约束

- **IO 约束**（`mc_pin.adc`）≈ STM32 CubeMX 里"哪个引脚复用成什么功能、输出什么电平"。
- **时序约束**（`mc_timing.sdc`）≈ STM32 的时钟树配置：告诉工具每个时钟多快，布线后检查"逻辑能不能跑到这个频率"。SDC **只是告诉工具，不会改变真实频率**。
- TD 里改：Hierarchy 里展开 `constraint_1`，双击 `mc_pin.adc` / `mc_timing.sdc` 直接改文本，保存（最稳）；或 **Tools → IO Constraint** / **Tools → Timing Wizard**。输入脚不能写 `DRIVESTRENGTH`。

## 9. 与厂商例程的差异（修改清单）

| 文件 | 改动 |
| --- | --- |
| `video/isp/isp_top.v` | 加 `IMG_WIDTH` / `IMG_HEIGHT` / `BAYER_MODE` 三个 parameter，替换原来写死的 1024 / 600 / "BGGR" |
| `video/isp/awb.v` | **增益计算重写**。原版：每个像素都把"本帧到目前为止"的累加和送进两个流水线除法器（`divider` IP），增益在帧内不停变（画面上面几行偏色跳），两个除法器占约 1400 LUT + 2200 进位 + 5500 寄存器（约全片 22% 的 slice）。现在：一帧里只累加（每拍第 0 个像素、R+G+B ≥ 720 的亮像素不算），帧开始时用一个移位相减的除法器（一位一个时钟）先后算 G/R、G/B，限幅 0~4.0，平滑（新 = 旧 + (算出 − 旧)/4），**下一帧整帧用同一组增益**。数据延迟线 `signal_delay`、乘增益和饱和、`O_tuser` 不延迟（下游 `video_in` 靠"帧开始到第一个像素"约 50 个时钟复位 FIFO）都和原版一样 |
| `ip/w8_d1024_rom/w8_d1024_rom.v` | `INIT_FILE` 改指向 `mc_ili9881c_k101.mif.dat`；该 IP 的 `.mif` / `.mif.dat` 由 `make_rom.ps1` 生成 |
| 不用的例程模块 | `video_source.v`、`mixer.v`（被 `mc_mixer.v` 替代）、2-lane 解包、SC500 配置、`image_correction.v`（被 `mc_crop.v` 替代）、`divider` IP |
| `video_in.v` `video_out.v` | **一字未改** |

## 10. 仿真与已知风险

- `tb_fb`：帧缓存（真实 `video_in` / `video_out` / 厂商 FIFO + 行为级 DDR）逐像素核对，含相机高速写的压力用例。
- `tb_mixer`：屏幕合成器（缩小版面，整帧逐像素核对，4 个实例）。
- `tb_awb`：白平衡用测试台自己的模型逐像素核对（统计规则、亮像素边界 720 / 719、除法、限幅、平滑、帧边界换增益、乘法饱和、帧开始到第一个输出像素 ≥ 45 个时钟、每行最后一拍的 `O_tlast`），26 帧覆盖偏色收敛 / 限幅 / 全亮帧 / 增益 < 1；做过 35 个突变检查。延迟线里的 RAM 用行为级替身（`sim/stubs/stub_awb_delay_ram.v`）。
- 厂商的 MIPI 收发、ISP 其余部分、DDR 控制器、DSI 打包核（加密）没法仿真，只能上板。
- TD 完整流程：slice 52%、LUT 47%、寄存器 26%、ERAM 38%、DSP 20%；SWNS +1.105 ns、HWNS +0.020 ns（2026-10-05）。
- **初始化脚本是按外形尺寸匹配的**（Linux 内核里 Feixin K101-IM2BYL02 的尺寸和这块屏一样），同尺寸的 ILI9881C 屏不止一种。§6 第一行改完还有条纹 / 压扁，就要商家的初始化代码。
- 取窗只覆盖传感器中心约 42% × 52%，不是完整视场。避障分析需要完整视场时，在 `mc_cam_if` 的 RAW10 流上并联一路抽取。

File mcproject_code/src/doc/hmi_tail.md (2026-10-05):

# 按键 / 文字层 / 尾巴 / 霍尔 / 行为层 说明

三个按键、屏幕中间状态带里的 3 行文字（像 OLED 一样显示英文和数字）、步进电机尾巴（UART 只发不收：上电自动回零 + 喂食时左右摇摆）、霍尔传感器（喂食检测）和行为层（喂食时摇尾巴 + 放进食音效）。**接线见 [`pinout.md`](pinout.md)**；音频见 [`audio.md`](audio.md)；屏幕版面见 [`video_pipeline.md`](video_pipeline.md) §4。轮子的控制不在 FPGA 里（放在另一块单片机上）。
状态：每个模块都有测试台，用 Icarus Verilog 仿真通过（`bash tools/sim.sh`）；整套 RTL 用 TD 跑通综合 + 布局布线。按键 / 尾巴 / 霍尔**上过板但当时尾巴没动**（原因见 §3），这一版改了以后**还没上板**。

---

## 1. 架构

```
SW1 SW2 SW3 ─► mc_key ──短按脉冲──► mc_bench（SW2/SW3 短按 → 相机增益键）
 (R10 N2 J14)   10 ms 扫描
   mc_osd_dash（把状态排成 3 行文字）──写总线──► mc_disp_if 里的 mc_mixer → mc_osd_text → 屏幕中间状态带

霍尔传感器 ─► mc_hall（同步 + 去抖 20 ms）─ 喂食 = 1 ─► mc_behavior（行为层）─ 摇尾巴脉冲 ─► mc_tail ─UART 115200（只发）─► ZDT X42S 步进驱动器 → 尾巴
 (CEP 脚 17)                                                  └ 音效命令（2.wav）──────► mc_audio
```

行为层 `mc_behavior`（以后避障、跟随的状态机也放在这一层）现在做两件事：**喂食（霍尔 = 1）时**，① 尾巴摇一个来回（约 0.6 秒），摇完检查一次，磁铁还在就再摇一个来回，拿开以后把当前这个来回摇完就停；② 进食音效播一遍（播放中不重复触发，磁铁不拿开也不重播，拿开再靠近才再播）。预留了 `I_near`（以后 UWB 距离 < 5 m 时也这样摇尾巴）和 `I_bark`（以后 UWB 丢了 / 太远就狗叫，一直为 1 就循环叫），现在顶层接 0。

- **没有"函数调用"，只有模块 + 端口**：每个模块是一块一直在运行的硬件，状态机"调用"它 = 给它的输入端口一个命令（电平或脉冲），再看它的输出端口（busy / 读数）。见 §5。
- 所有模块跑在 100 MHz 系统时钟域，用 `mc_tick` 的 1 ms / 10 ms / 100 ms 脉冲做节拍（按键 10 ms 扫描、尾巴按 1 ms 计时、屏幕文字 100 ms 刷新）。

## 2. 文件清单（相对 `src/rtl/`，全部自写）

| 路径 | 作用 |
| --- | --- |
| `hmi/mc_key.v` | 按键扫描：去抖 20 ms，**短按**（松手时一个脉冲）、**长按**（按住 0.8 s 时一个脉冲）、按下/按住电平。3 个键并行。逻辑照搬 TI2026H 的 `key.c` |
| `hmi/mc_bench.v` | 台架按键：SW2 / SW3 短按 → 40 ms 低电平脉冲 → 相机增益 +1 / -1。**只是调试用**，以后状态机直接产生增益键就拿掉 |
| `sensor/mc_hall.v` | 霍尔传感器输入：同步（2 级触发器）+ 去抖（默认 20 ms）→ `O_fed`（1 = 磁铁靠近 = 喂食中）。磁铁靠近模块输出高电平 |
| `app/mc_behavior.v` | 行为层：喂食时让尾巴摇一个来回再检查、播一遍进食音效（规则见 §1）；`I_near` / `I_bark` 预留给 UWB |
| `system/mc_hold_reset.v` | SW1 按住 2 s → 复位 PLL（整机复位） |
| `comm/mc_uart_tx.v` | 串口发送 8N1，波特率参数化 |
| `tail/mc_stepper_emm.v` | ZDT X42S（Emm 固件）的帧生成，只发不收：解除保护、使能、位置运动、**单圈就近回零**、**设坐标零点**（字节按驱动器手册第 5 章） |
| `tail/mc_tail.v` | 尾巴动作：**上电自动回零**（解除保护 → 使能 → 单圈就近回零 → 等 2 s → 设坐标零点）、**摇摆**（中→左 30°→中→右 30°→中）。命令口只有"摇摆"；回零做完之前不接受摇摆 |
| `video/osd/mc_font8x16.v` | ASCII 8×16 字库 ROM（**自动生成**，来源是 TI2026H 的 OLED 字库 `asc2_1608`，生成脚本 `tools/gen_font.sh`） |
| `video/osd/mc_osd_text.v` | 文字层：字符 RAM（45 列 × 3 行）+ 逐像素渲染；跨时钟域（100 MHz 写，像素时钟读） |
| `video/osd/mc_osd_clear.v` | 清屏：复位后把整个文字框写成空格 |
| `video/osd/mc_osd_dash.v` | **文字版面**（3 行，一页）。**由 `tools/gen_osd_dash.pl` 生成，不要手改**：每个项目（固定字符串 / 状态名 / 数字）是项目表里的一行，一个序列器每 100 ms 把项目逐个写进字符 RAM，所有数字共用一个二进制→十进制转换器 |

## 3. 尾巴：上电回零，以及上次上板尾巴为什么没动

**上电回零是怎么做的**：驱动器的"坐标零点"= 它上电那一刻的位置，所以以前发"回到绝对位置 0"等于原地不动（上次上板"上电没归位"就是这个原因）。现在改用驱动器自己的**单圈就近回零**（手册 5.4.2，`01 9A 00 00 6B`）：驱动器带单圈绝对编码器，会转到它存的"回零零点"，最多转半圈；FPGA 等 2 秒（`TAIL_HOME_MS`）再发"设坐标零点"（`01 0A 6D 6B`），之后摇摆的"绝对位置 0"就是正中。上电（和 SW1 按住 2 秒整机复位）后 1 秒（`TAIL_INIT_MS`）自动做一遍。

**回零零点要先在驱动器上设一次**（掉电不丢）：先拔掉 FPGA 到驱动器 R/A/H 的那根线 → 驱动器断电 → 用手把尾巴拧到正中 → 驱动器上电 → 驱动器菜单 `0_Set` → `Set 0` → 插回线。

**霍尔 = 1 时尾巴也没动，最可能是串口没通**（FPGA 发出去驱动器没收到）。逐条查：
1. 线：FPGA 的 CEP **脚 15**（E17）接驱动器的 **R/A/H** 脚（不是 T/B/L）；驱动器的 **Gnd 接 CEP 脚 2**。不共地串口收不到。
2. 驱动器必须是**串口 TTL 版本**（RS485 版本的 R/A/H 是差分电平）。
3. 驱动器菜单（出厂值）：`FWType = FW_Emm`（小屏第二行显示 `0.00err` 就是 Emm 固件）、`P_Serial = UART_FUN`、`UartBaud = 115200`、`ID_Addr = 1`、`Checksum = 0x6B`。
4. 驱动器电源 10~29 V 要接着（只插 FPGA 那根线它不会动）；小屏有显示、没报 `Clogging Protect`（堵转保护，FPGA 上电会先发解除保护）。
5. 确认霍尔真的到了 FPGA：屏幕中间第 1 行 `HALL 1`；看不到屏幕时，喂食时右喇叭会放 2.wav（音效和尾巴是同一个触发）。
6. 还不动：用 USB 转 TTL 模块接驱动器，在串口助手里手动发 `01 F3 AB 01 00 6B`（使能）、`01 FD 01 00 50 00 00 00 01 0B 01 00 6B`（转 30°），驱动器动了说明驱动器没问题、问题在 FPGA 这一侧的线。

## 4. 按键、屏幕文字、LED

| 键 | 功能 |
| --- | --- |
| SW1 短按 | 无 |
| **SW1 按住 2 秒** | **整机复位**（顶层 `mc_hold_reset`；尾巴会重新回零、背景音乐重新开始） |
| SW2 短按 / SW3 短按 | 相机增益 +1 / -1（台架把短按变成 40 ms 低电平脉冲送给相机增益模块 `ae_set`） |
| 各键长按 | 无 |

屏幕中间状态带（v 560~719）：上面 8 个状态方块（见 `video_pipeline.md` §4），下面 3 行文字（45 列，每个字符 16×32 像素，黑底白字）：

```
GAIN 050  HALL 0  TAIL IDLE KEY 000 UP 00123s      相机增益 / 霍尔（1 = 磁铁靠近）/ 尾巴（IDLE 空闲 HOME 回零 WAG 摇摆）/ 三个键的电平 / 开机秒数
SD READY  CODEC OK    BGM PLAY  SFX IDLE           TF 卡 / ES8388 / 背景音乐 / 音效（含义见 audio.md）
K3 SHORT  SW2 gain+ SW3 gain- SW1 2s reset         最近一次按键事件 / 按键提示
```

### 4.1 LED 的含义（没有屏幕、或屏幕不亮时）

| LED | 现象 | 含义 |
| --- | --- | --- |
| LED1 | 约 1 Hz 闪 | PLL 锁定、节拍正常（FPGA 在正常跑）。不闪 = 没配置好 / 时钟没起来 |
| LED2 | 灭 | DDR2 还没校准完（或校准失败） |
| | 约 2 Hz 闪 | DDR2 校准好了，屏幕初始化脚本还没发完 |
| | **常亮** | DDR2 校准好 + 屏幕初始化脚本发完。**没接屏幕也会常亮**（脚本只往屏幕写、不等应答） |
| LED3 | 灭 | 相机寄存器还没配完 |
| | 约 2 Hz 闪 | 相机寄存器配完了，但没有图像帧进来（**没接相机就是这样**） |
| | 常亮 | 图像帧持续进入帧缓存（相机、MIPI、ISP 都正常） |

### 4.2 上电以后应该看到什么

1. LED1 闪；约 0.3 s 后屏幕背光亮、状态方块和文字出现；LED2 常亮。接了相机：LED3 常亮，屏幕上半部分出现实时画面。
2. 约 1 秒：尾巴自己转到回零零点（正中）；屏幕 `TAIL HOME` 约 2 秒后回到 `IDLE`。
3. 约 1 秒：左喇叭（J12）开始放 1.wav，循环。
4. 磁铁靠近霍尔：`HALL 1`，尾巴摇一个来回（磁铁还在就继续摇），右喇叭（J11）放一遍 2.wav。

## 5. 在状态机里怎么"调用"（接口速查）

Verilog 里没有函数调用。对应关系：**函数 = 模块；调用 = 给输入端口赋值；参数 = 输入端口或 parameter；返回值 = 输出端口；`delay_ms` 阻塞 = 状态机里数 tick**。

| 模块 | 输入（你给） | 输出（你读） |
| --- | --- | --- |
| `mc_key` | `I_key[2:0]`（引脚）、`I_tick`（10 ms） | `O_short[i]` 短按脉冲、`O_long[i]` 长按脉冲、`O_pressed[i]` 按着中、`O_down[i]` 按下确认脉冲 |
| `mc_tail` | `I_cmd_wag` 脉冲（空闲且回零做完才收） | `O_busy`、`O_seq`（0 空闲 1 回零 2 摇摆） |
| `mc_audio` | `I_sfx_play` + `I_sfx_clip`（1~64）脉冲 | `O_ready`、`O_bgm_state` / `O_sfx_state`（0 空闲 1 打开中 2 播放中 3 出错）、`O_sfx_busy` 等（`audio.md` §5） |
| `mc_hall` | `I_hall`（引脚）、`I_tick_1ms` | `O_fed`（1 = 磁铁靠近，已去抖） |
| `mc_behavior` | `I_hall`（喂食）、`I_near` / `I_bark`（预留）；`I_audio_ready` `I_sfx_busy` `I_sfx_state` `I_tail_busy`（反馈） | `O_tail_wag`（接 `mc_tail`）、`O_sfx_play` + `O_sfx_clip`（接 `mc_audio`） |
| `mc_bench` | `I_key_short`、`I_tick_10ms` | `O_cam_key_n`（相机增益键） |
| `mc_osd_dash` | 各种状态量、`I_tick_1ms` `I_tick_100ms` | 写总线 `O_bus`（接 `mc_osd_text`） |

屏幕加一项显示：改 `tools/gen_osd_dash.pl` 里的 `@ITEMS`（一行 = 一个项目：固定字符串 / 状态名 / 数字，写明行、列、位数），要显示新的信号就在 `@SRC`（数字）或 `%SELID`（状态名）里加取值来源，并给 `mc_osd_dash` 加一个输入端口，然后 `perl tools/gen_osd_dash.pl > mcproject_code/src/rtl/video/osd/mc_osd_dash.v` 重新生成。

## 6. 参数在哪改（`mctop.v` 配置区）

| 想改什么 | 参数 |
| --- | --- |
| 尾巴摆幅、减速比、方向、转速、每段时间 | `TAIL_SWING_DEG` `TAIL_GEAR_X100` `TAIL_LEFT_CCW` `TAIL_RPM` `TAIL_LEG_MS` |
| 上电多久开始回零、等回零走完的时间 | `TAIL_INIT_MS`（1000）、`TAIL_HOME_MS`（2000；驱动器回零转速默认 30 RPM，最多转半圈 = 1 秒） |
| 长按判定时间、SW1 复位时长 | `KEY_LONG_MS`、`RST_HOLD_MS` |
| 文字区位置、大小、字号 | `OSD_X0` `OSD_Y0` `OSD_COLS` `OSD_ROWS`（版面按 45 列 × 3 行排）`OSD_SH`（字符放大 2^SH 倍） |
| 霍尔传感器去抖 | `HALL_DEBOUNCE_MS`（20） |
| 摆幅脉冲数 | `SWING_PULSES = 3200 × 减速比 × 角度 / 360`，默认直驱 30° = 267 脉冲 |

## 7. 仿真

`bash tools/sim.sh` 跑 `src/sim/` 下的测试台（每个最后打印 PASS / FAIL；默认 17 个约 25 分钟，跳过最慢的三个：`tb_top`（约 15 分钟）、`tb_audio`（约 30 分钟）、`tb_fb`（约 2 分钟），点名跑：`bash tools/sim.sh tb_top`，或 `ALL=1 bash tools/sim.sh` 全跑；多个一起跑时各设一个 `SIM_OUT=<目录>` 并行）。需要 Icarus Verilog（`winget install Icarus.Verilog`，或设置环境变量 `IVERILOG_HOME`）。

| 测试台 | 覆盖 |
| --- | --- |
| `tb_key` | 去抖、短按、长按（精确 80 个节拍）、毛刺、复位时已被按住、连续短按 |
| `tb_hold_reset` | 按住够久才复位、短按不触发、按住不重复触发 |
| `tb_uart` | 线上的每个字节（独立解码）、起始 / 停止位、每一位的宽度（精确到 1 个时钟）、背靠背 10 位间隔、忙时来的 valid 不收、空闲为高 |
| `tb_tail` | 上电回零：到点时刻、19 个字节逐字节、回零帧和设零点帧之间隔 `HOME_MS`、其他帧之间隔 `GAP_MS`、只做一遍；回零做完之前（到点前 / 回零中）的摇摆请求不理也不排队；摇摆 58 字节逐字节 + 段间隔 `LEG_MS`、摇摆中再给命令不理；`O_seq` 取值；复位后重新回零；第二个实例换一组参数（地址 / 方向 / 减速比 / 摆幅 / 转速 / 加速度）核对摇摆帧；发送线用测试台自己的解码器检查位宽 |
| `tb_osd` | 字符 RAM 内容、对整个文字框逐像素比对（延迟/放大/坐标）、字符画目检、总线写入 / 复位后整框清屏 |
| `tb_dash` | 整块字符 RAM（135 个字符）和测试台里按版面规则拼出来的期望逐字符比较：第一遍在复位后约 1 ms 内画完、之后每个 100 ms 节拍恰好一遍；数字转换（位数不够只显示低位、0、最大值、前导零）；所有状态名和未定义状态值（背景音乐和音效取不同的值）；三个键的 8 种电平组合、最近一次按键事件（含优先级）、开机秒数自己数 |
| `tb_bench` | SW2 / SW3 短按 → 对应的增益键低电平正好 4 个节拍；SW1 不出脉冲；两个一起按；脉冲中再按重新计时 |
| `tb_top` | **顶层集成**（视频的 PLL / 相机 / 帧缓存 / 显示接口用替身，其余是真的，外面接行为级 TF 卡和 ES8388）：配置区的版面 / 音量参数真的送到下游；上电尾巴回零 19 字节逐字节；按键 → 相机增益键（脉冲宽度）；按住键时文字显示按着的键；背景音乐上电自动响（第一个采样核对曲目号）；三行文字整行核对；**喂食：两个来回 116 字节逐字节 + 进食音效 2.wav 只播一遍，拿开再靠近才再播**；LED 真值表；**接线核对**：状态方块 / 文字面板的输入口用 `force` 给互不相同的值，行为层 ↔ 尾巴 / 音频 / 霍尔、按键 → 台架 → 相机等连线每个时钟比较两端；SW1 按住整机复位后尾巴重新回零、背景音乐重新开始 |
| `tb_hall` | 霍尔输入：去抖（毛刺不通过、第 5 个节拍正好翻转、不早不晚）、反复抖动、上电时磁铁就在旁边、复位值 |
| `tb_behavior` | 行为层：音频没准备好就等着；音效只触发一次、播放中不重复触发；磁铁一直在 → 尾巴一个来回接一个来回，拿开后摇完当前来回就停；`I_near` 也摇；出错结束后不重试；进食和狗叫冲突时排队，`I_bark` 一直为 1 就循环叫；复位 |
| `tb_mixer` `tb_fb` `tb_awb` | 屏幕合成、帧缓存、白平衡（`video_pipeline.md` §10） |
| `tb_i2s` `tb_es8388` `tb_sdfat` `tb_sdarb` `tb_sdarb_proto` `tb_audio_mix` `tb_audio` | 音频各层（`audio.md` §8） |

测试台验证的是 RTL 的逻辑；**它们不能替代上板**（引脚电平、驱动器真实响应、机械方向、真实 DDR 的读效率、真实 TF 卡的兼容性都要实测）。

**突变检查**（故意改坏 RTL 一处，测试台必须报 FAIL）：每个自写模块的接线、状态机、地址运算、边界条件都做过，抓到的测试台漏洞都已补上。下面是**没被抓到的等价突变**（改了以后外部行为一模一样，或者改的是重复的保险），以后别再追：

| 改坏的地方 | 为什么抓不到（不是测试台的漏洞） |
| --- | --- |
| `mc_tail`：`S_homed`（回零做完）在任何动作结束时置 1 / 在回零开始时就置 1 | `S_homed` 只在空闲时看；回零是上电后第一个动作，回零期间状态机不空闲，两种写法对外一样 |
| `awb`：本帧增益寄存器的复位值改成 2.0 | 第一个帧开始时就被换成"下一帧增益"（1.0），在那之前没有像素用到它 |
| `mc_hall`：把同步后的输入 `S_sync[1]` 换成 `S_sync[0]`（少一级同步） | 仿真里没有亚稳态，只差一个时钟，去抖是按毫秒数的；少一级同步的代价只在真实硬件上，所以保留两级 |
| `mc_hall`：翻转时 `O_fed <= S_in` 写成 `O_fed <= ~O_fed` | 翻转的条件是 `S_in != O_fed`，这时 `S_in` 就等于 `~O_fed` |
| `mc_mixer`：帧起始处锁存相机帧标志时，用 `I_vsync` 的电平代替上升沿 | vsync 脉冲期间不在有效视频里，锁存发生在脉冲开头还是结尾，窗口都在这之后才开始读 |
| `mc_audio_mix`：原生采样率（≥ 47500 Hz）的"每帧取一次"写成"每帧加 FS8 + 1" | 原生采样率下取样判断恒为真；累加值要连续播 13 秒以上才会溢出 20 位 |
| `mc_osd_dash`（生成的文字面板）：字符串项目的长度字段 +1，而这个项目后面紧挨着（同一行、下一格）就是下一个项目：`"GAIN "` `"HALL "` `"TAIL "` `"KEY "` `"UP "` `"SD "` `"CODEC "` `"BGM "` `"SFX "`、开机秒数多一位（被 `"s"` 盖掉）；`"s"`（多写的落在第 45 列，文字区外）；按键提示（多写的是空格） | 序列器按项目表的顺序写，多写的那一格随后被下一个项目覆盖，每 100 ms 只在写的那几百纳秒里错一格（`"GAIN "` 那一条在测试里碰巧在这几百纳秒里取样被抓到过）。别的项目的列 +1、行 −1、选择器 +1、文字表地址 +1、取值来源 +1 全部被抓到 |
| `mc_osd_dash`：去掉写字符条件里的"上游空闲"（`!S_ib[19]`） | 序列器推进的条件本来就检查 `!S_ib[19]`，总线数据选择也是清屏优先；重复的保险 |
| `mc_osd_dash`：数字右对齐的结束条件 `>= 5`（BCD 位数）改成 `>= 4` 或 `>= 6` | 少 / 多等一个时钟：移位条件是独立的 `< 5`，总移位次数不变 |
| `mc_fat_dir`：不再检查目录项属性 0x0F（长文件名项）/ 首字节 0xE5（已删除） | 这两种目录项的第一个字节不可能是数字，名字解析本来就拒绝了；重复的保险 |
| `mc_fat32`（外壳）：读取器 1 的"总线忙"接成 0 号口的 | 读取器自己的状态机在上一次读完之前不会发新命令，"忙"只是重复的保险 |
| `mc_fat32` / `mc_audio`：读取器 1 的字节序号接成 0 号口的 | 仲裁器的 `O_idx0` 和 `O_idx1` 本来就是同一根线 |
| `mc_audio`：I2S 发送器的 `I_valid` 接常数 1 | 混音器的 `O_valid` 复位后恒为 1（缺数据时补静音）；重复的保险 |
| `mc_wav_player`：重新打开（循环 / 新的播放命令）前 `P_STOPPING` 不清空环形缓冲 | `P_START` 还会再清一次，对外不可见 |
| `mc_sd_arb`：`S_free` 去掉 `~O_start`；`O_valid1` 去掉 `S_act`；发出命令那一拍丢掉"同一拍又来的新请求"；`else if (S_free)` 改成 `if (S_free)` | 都是重复的保险或用不到的情况（见 `audio.md` §8 的协议级测试 `tb_sdarb_proto`） |
| 顶层 `mctop.v`：行为层的 `I_audio_ready` 接 1 | `tb_top` 里喂食总发生在音频准备好之后；"没准备好就等着"由 `tb_behavior` 覆盖 |
| 顶层 `mctop.v`：行为层的 `I_sfx_state` 接 0 | 只用来判断"狗叫是不是正常播完"，而顶层的 `I_bark` 现在接 0（UWB 还没做）；由 `tb_behavior` 覆盖。**接上 UWB 以后要在 `tb_top` 里补一个狗叫循环的用例** |

另外，`tb_top` 为了跑得快用 `defparam` 把尾巴的 `HOME_MS` / `LEG_MS` / `GAP_MS` / `INIT_DELAY_MS`、按键 / 霍尔的去抖时间压缩了，所以**顶层把这几个参数接没接上**在 `tb_top` 里看不出来（它们的作用由 `tb_tail` / `tb_key` / `tb_hall` 用真实的写法覆盖）。改 `mctop.v` 里的 `TAIL_*` 参数时自己核对一下例化处。

## 8. 已知限制 / 上板要验证的

- **尾巴回零**：回零命令和设零点命令的字节按手册第 5 章逐字节核对过；"回零走完"是**定时**的（等 `TAIL_HOME_MS` 2 秒），不读驱动器的回零完成应答（串口只发不收）。驱动器的回零转速改得很慢（菜单 `0_Vel`）的话要把 `TAIL_HOME_MS` 加大。
- 摇摆也是**定时**的（每段等 `TAIL_LEG_MS`），不等驱动器"到位"应答。换电机 / 加减速后要重新估算这个时间。
- 驱动器上电比 FPGA 晚超过 1 秒（`TAIL_INIT_MS`）的话，回零命令发出去时它还没准备好：先给驱动器上电，或者上电后 SW1 按住 2 秒整机复位再回零一次。
- SW1 按住 2 秒整机复位，状态机里不要用"SW1 按住超过 2 秒"表示别的操作。
- 文字区的 RAM 在 100 MHz 域写、像素时钟读，没有握手：某个字符恰好在被写的那一刻被读到，那一帧会显示旧值/乱码，下一帧恢复。

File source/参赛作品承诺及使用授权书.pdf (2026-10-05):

下载打印并全体队员签名后扫描提交

## 参赛作品承诺及使用授权书

队伍编号 | 的全体成员为 | ，
本队自愿参加“ | 年全国大学生嵌入式芯片与系统设计
竞赛”并提交作品。
现本队向竞赛组委会及组织单位郑重承诺：
第一，本队所提交的参赛作品为原创设计或已获得知识
产权权属方的合法授权，不存在任何侵权行为。如有侵权行 为发生，本队将承担全部责任，并赔偿竞赛组委会及组织单 位造成的损失。
第二，本队所提交的参赛作品不含涉及国家、军事、学
校、实验室商业秘密及个人隐私，授权本次竞赛组委会和组 织单位有权对本队的演示视频、作品报告、作品实物、比赛 现场拍摄照片等享有网站发布、对外展示、媒体宣传、整理 汇编出版等权利，但应在作品上署本队信息。
特此承诺和授权。
| 授权人（全体队员签名）： 被授权人：大赛组委会、分赛区

主办单位、承办单位、运营单位
| 参赛队伍所选协办单位 日期：

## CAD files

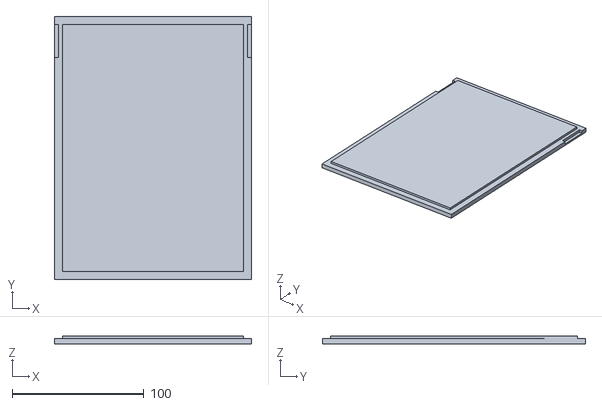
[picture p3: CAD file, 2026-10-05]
3Dmodel/stls/body_cover.stl
150.0 x 200.0 x 6.00

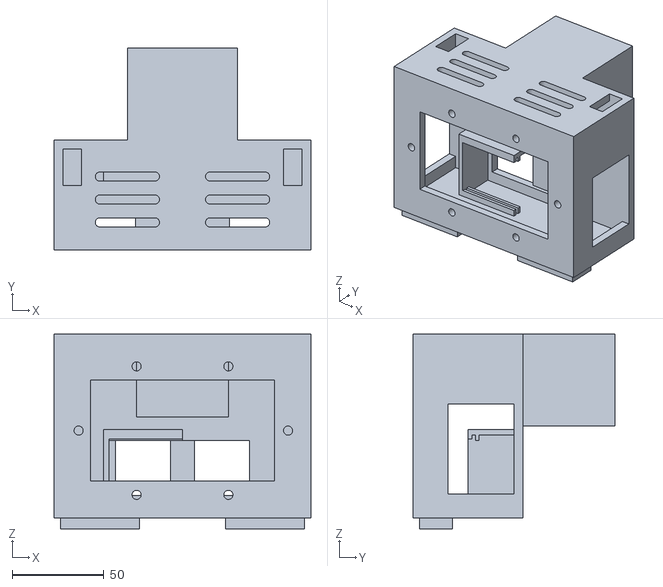
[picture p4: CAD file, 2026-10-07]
3Dmodel/stls/re/head.stl
140.0 x 110.0 x 106.0

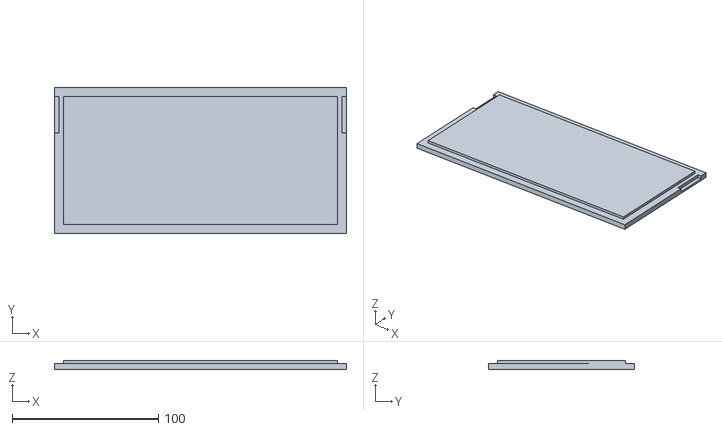
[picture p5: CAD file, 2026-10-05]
3Dmodel/stls/breast_cover.stl
200.0 x 100.0 x 6.00

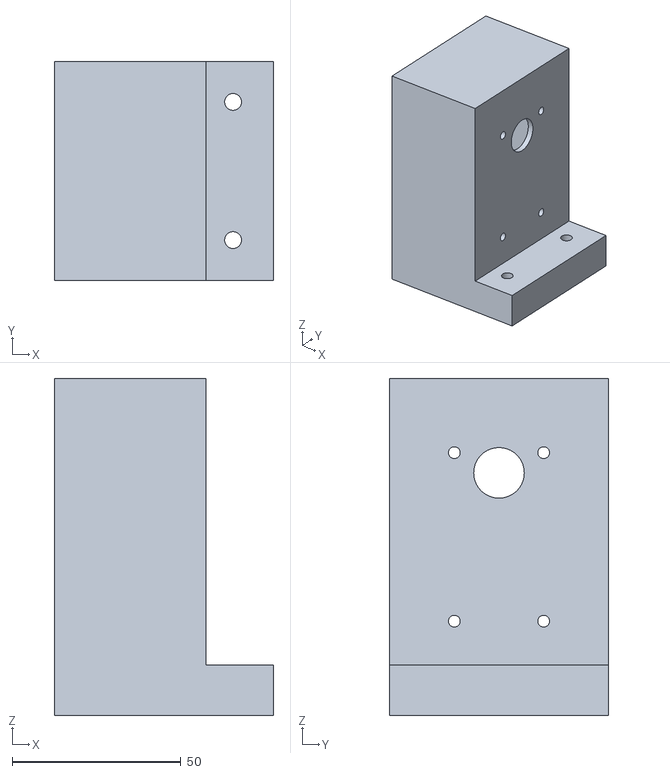
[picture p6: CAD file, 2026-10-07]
3Dmodel/stls/re/left_back.stl
65.0 x 65.0 x 100.0

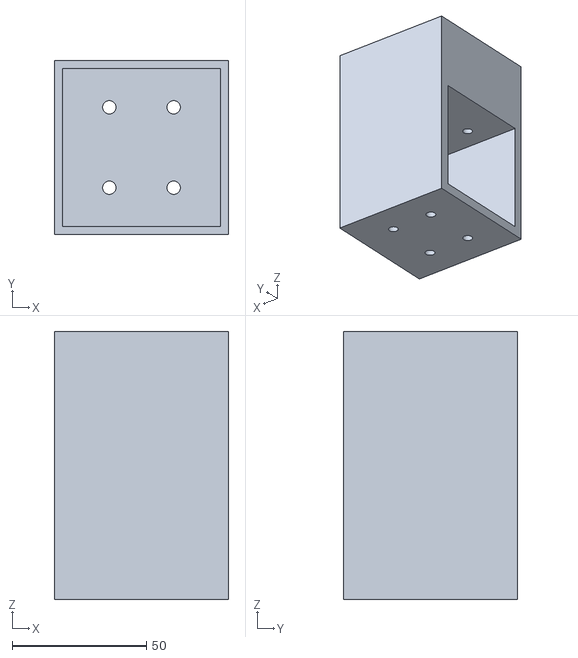
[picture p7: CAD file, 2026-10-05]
3Dmodel/stls/left_front.stl
65.0 x 65.0 x 100.0

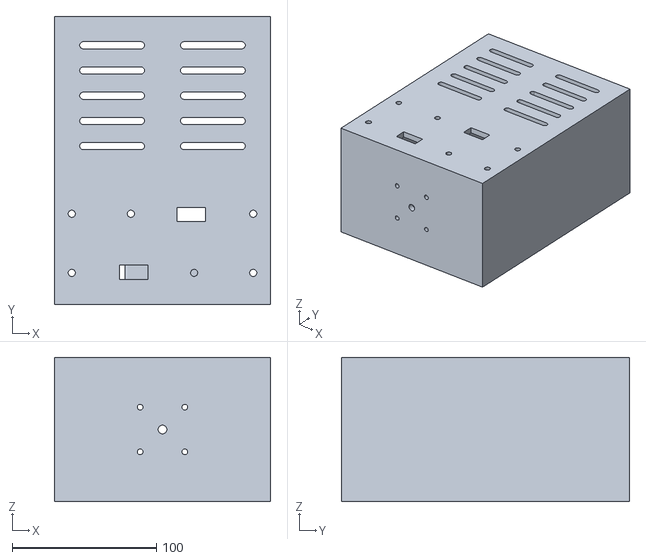
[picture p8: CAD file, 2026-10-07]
3Dmodel/stls/re/body.stl
150.0 x 200.0 x 100.0

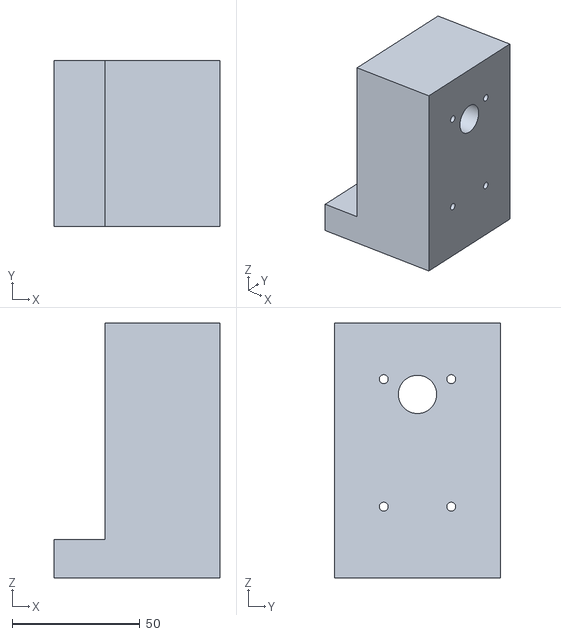
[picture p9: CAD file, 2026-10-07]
3Dmodel/stls/re/right_back.stl
65.0 x 65.0 x 100.0

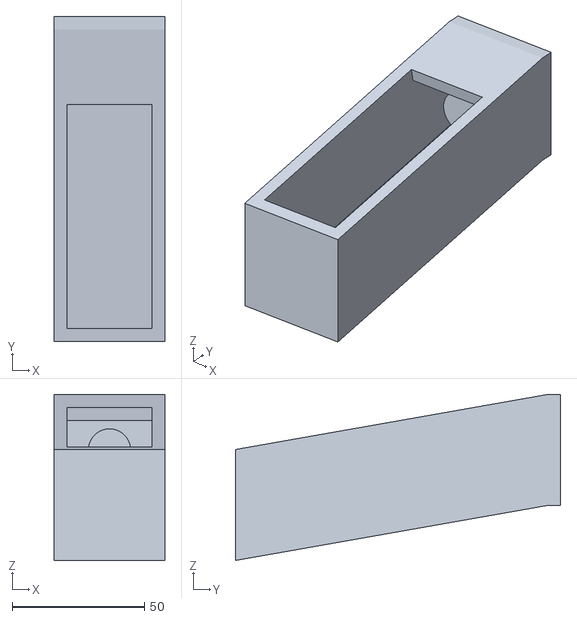
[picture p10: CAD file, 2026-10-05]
3Dmodel/stls/tail.stl
42.0 x 123.2 x 62.8

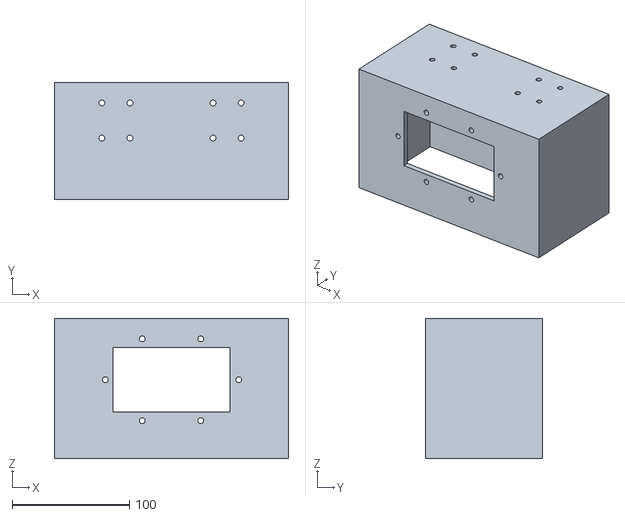
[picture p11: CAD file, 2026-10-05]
3Dmodel/stls/breast.stl
200.0 x 100.0 x 120.0

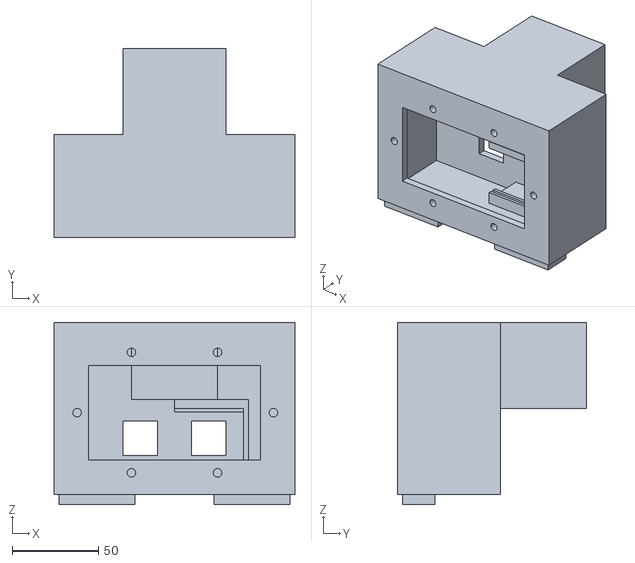
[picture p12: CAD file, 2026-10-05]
3Dmodel/stls/head.stl
140.0 x 110.0 x 106.0

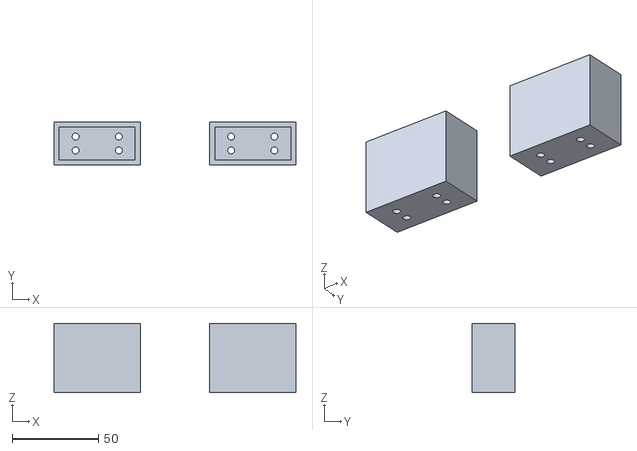
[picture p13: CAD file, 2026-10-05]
3Dmodel/stls/ears.stl
140.0 x 25.0 x 40.0

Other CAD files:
3Dmodel/stls/right_front.stl
3Dmodel/stls/body.stl
3Dmodel/stls/left_back.stl
3Dmodel/stls/right_back.stl
3Dmodel/MinecraftDog_3Dmodel.f3d

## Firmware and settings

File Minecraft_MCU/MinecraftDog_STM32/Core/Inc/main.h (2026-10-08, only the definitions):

#define UWB_L_U2TX_Pin GPIO_PIN_2
#define UWB_L_U2TX_GPIO_Port GPIOA
#define UWB_L_U2RX_Pin GPIO_PIN_3
#define UWB_L_U2RX_GPIO_Port GPIOA
#define FPGA_U3TX_Pin GPIO_PIN_10
#define FPGA_U3TX_GPIO_Port GPIOB
#define FPGA_U3RX_Pin GPIO_PIN_11
#define FPGA_U3RX_GPIO_Port GPIOB
#define AIN1_Pin GPIO_PIN_12
#define AIN1_GPIO_Port GPIOB
#define AIN2_Pin GPIO_PIN_13
#define AIN2_GPIO_Port GPIOB
#define BIN1_Pin GPIO_PIN_14
#define BIN1_GPIO_Port GPIOB
#define BIN2_Pin GPIO_PIN_15
#define BIN2_GPIO_Port GPIOB
#define E1A_Pin GPIO_PIN_6
#define E1A_GPIO_Port GPIOC
#define E1B_Pin GPIO_PIN_7
#define E1B_GPIO_Port GPIOC
#define KEY2_Pin GPIO_PIN_8
#define KEY2_GPIO_Port GPIOC
#define KEY1_Pin GPIO_PIN_9
#define KEY1_GPIO_Port GPIOC
#define LED_Pin GPIO_PIN_8
#define LED_GPIO_Port GPIOA
#define E2A_Pin GPIO_PIN_15
#define E2A_GPIO_Port GPIOA
#define UWB_F_U4TX_Pin GPIO_PIN_10
#define UWB_F_U4TX_GPIO_Port GPIOC
#define UWB_F_U4RX_Pin GPIO_PIN_11
#define UWB_F_U4RX_GPIO_Port GPIOC
#define UWB_R_U5TX_Pin GPIO_PIN_12
#define UWB_R_U5TX_GPIO_Port GPIOC
#define UWB_R_U5RX_Pin GPIO_PIN_2
#define UWB_R_U5RX_GPIO_Port GPIOD
#define E2B_Pin GPIO_PIN_3
#define E2B_GPIO_Port GPIOB

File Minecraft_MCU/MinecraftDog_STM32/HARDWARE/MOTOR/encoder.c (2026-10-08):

#include "encoder.h"

#include "tim.h"

/* 硬件计数: TIM8 = 左轮, TIM2 = 右轮 (CubeMX 里都是 Encoder Mode TI1 and TI2, 0~65535)。
 * 不再用中断数边沿, temp_count 也就用不上了; encoder_update() 用"这次读数 - 上次读数"
 * 算本周期计数, 按 int16_t 相减自动处理 65535 <-> 0 的回绕
 * (前提: 两次 encoder_update 之间单轮不超过 32767 个计数)。 */
#define ENCODER_LEFT_TIM   (&htim8)
#define ENCODER_RIGHT_TIM  (&htim2)

static ENCODER_RES motorL_encoder;
static ENCODER_RES motorR_encoder;

static uint16_t g_encoderL_last = 0U;
static uint16_t g_encoderR_last = 0U;

void encoder_init(void)
{
    motorL_encoder.temp_count = 0;
    motorL_encoder.count      = 0;
    motorL_encoder.dir        = FORWARD;
    motorL_encoder.ALLcount   = 0;

    motorR_encoder.temp_count = 0;
    motorR_encoder.count      = 0;
    motorR_encoder.dir        = FORWARD;
    motorR_encoder.ALLcount   = 0;

    HAL_TIM_Encoder_Start(ENCODER_LEFT_TIM, TIM_CHANNEL_ALL);
    HAL_TIM_Encoder_Start(ENCODER_RIGHT_TIM, TIM_CHANNEL_ALL);
    g_encoderL_last = (uint16_t) __HAL_TIM_GET_COUNTER(ENCODER_LEFT_TIM);
    g_encoderR_last = (uint16_t) __HAL_TIM_GET_COUNTER(ENCODER_RIGHT_TIM);
}

ENCODER_DIR get_encoderL_dir(void)
{
    return motorL_encoder.dir;
}

ENCODER_DIR get_encoderR_dir(void)
{
    return motorR_encoder.dir;
}

void Encoder_Get_ALL(int *Encoder_all)
{
    if (Encoder_all == 0) {
        return;
    }

    Encoder_all[0] = motorL_encoder.ALLcount;
    Encoder_all[1] = motorR_encoder.ALLcount;
}

void Encoder_Get_Temp(int *Encoder_temp)
{
    if (Encoder_temp == 0) {
        return;
    }

    Encoder_temp[0] = motorL_encoder.count;
    Encoder_temp[1] = motorR_encoder.count;
}

/* 里程计累计: 左右轮"本周期计数"之和(读数时再除以 2 取平均, 避免整数除法丢精度)。
 * 累加点放在 encoder_update() 内部, 这样不管周期调用者是谁(里程任务 / 速度环
 * MotorPID_Run), 里程都会自动跟着走, 不用两处各记一份。 */
static long g_odom_sum = 0;

void encoder_update(void)
{
    uint16_t left_now  = (uint16_t) __HAL_TIM_GET_COUNTER(ENCODER_LEFT_TIM);
    uint16_t right_now = (uint16_t) __HAL_TIM_GET_COUNTER(ENCODER_RIGHT_TIM);
    int16_t left_temp  = (int16_t) (left_now - g_encoderL_last);
    int16_t right_temp = (int16_t) (right_now - g_encoderR_last);

    g_encoderL_last = left_now;
    g_encoderR_last = right_now;

    motorL_encoder.count = (int) left_temp;
    motorR_encoder.count = (int) right_temp;

    motorL_encoder.ALLcount += motorL_encoder.count;
    motorR_encoder.ALLcount += motorR_encoder.count;

    motorL_encoder.dir = (motorL_encoder.count >= 0) ? FORWARD : REVERSAL;
    motorR_encoder.dir = (motorR_encoder.count >= 0) ? FORWARD : REVERSAL;

    /* ★★ 必须过一遍方向符号 ★★ (2026-07-31 修)
     * 左右编码器的正方向不一定相同 —— 本车 motor_pid_enc_sign_r 就是 -1, 即前进时
     * 右侧读【负】数。原来是把两个【原始】计数直接相加, 结果是 +N + (-N) ≈ 0:
     *     g_odom_sum 恒等于 0 -> Encoder_Odom_GetM() 恒等于 0
     *     -> mode_3 的"里程 >= 1.5m"判据【永远不会触发】
     *     -> 只能靠"转角 >= 12 度"兜底 -> 直道上画一下龙就停了(实测"没到 B 就停")
     * 方向符号现在由 encoder.h 的 ENCODER_*_FORWARD_SIGN 统一配置，后续速度环
     * 直接读取已经校正过的速度/里程即可，不再依赖尚未创建的算法文件。 */
    g_odom_sum += (long) (ENCODER_LEFT_FORWARD_SIGN * motorL_encoder.count)
                + (long) (ENCODER_RIGHT_FORWARD_SIGN * motorR_encoder.count);
}

/* ==========================================================================
 * 里程计 —— 见 encoder.h 顶部说明。★ encoder_counts_per_meter 必须上车标定 ★
 * ========================================================================== */
float encoder_counts_per_meter = 3800.0f;   /* 猜的起点值, 标定后改这里(含符号) */

void Encoder_Odom_Reset(void)
{
    encoder_update();       /* 先把上次残留的计数吃掉, 从干净的 0 开始 */
    g_odom_sum = 0;
}

void Encoder_Odom_Update(void)
{
    encoder_update();       /* 累加在 encoder_update() 内部完成 */
}

long Encoder_Odom_GetCount(void)
{
    return g_odom_sum / 2;  /* 左右平均计数, 标定时看这个数 */
}

float Encoder_Odom_GetM(void)
{
    if ((encoder_counts_per_meter > -1.0f) && (encoder_counts_per_meter < 1.0f)) {
        return 0.0f;        /* 未标定/非法, 返回 0 而不是除爆 */
    }

    return (float) g_odom_sum / (2.0f * encoder_counts_per_meter);
}

/* 最近一次采样的左右速度(编码器本周期计数, 带符号) */
volatile int g_speed_left  = 0;
volatile int g_speed_right = 0;

void Encoder_Speed_Sample(void)
{
    int temp[2];

    encoder_update();               /* 读并清零本周期计数 */
    Encoder_Get_Temp(temp);         /* [0]=左, [1]=右 */
    g_speed_left  = temp[0];
    g_speed_right = temp[1];
}

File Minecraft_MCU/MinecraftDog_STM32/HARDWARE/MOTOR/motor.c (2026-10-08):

#include "motor.h"
#include "delay.h"
#include "tim.h"

/* 电机锁: 0=关(默认, 强制停机), 1=开(允许 PWM_Control_Car 驱动) */
static uint8_t g_motor_lock = 0U;

static uint16_t Motor_Limit_PWM(uint16_t motor_speed)
{
    if (motor_speed > MAX_SPEED) {
        return MAX_SPEED;
    }

    return motor_speed;
}

static int16_t Motor_Ignore_Dead_Zone(int16_t speed)
{
    if (speed > 0) {
        return speed_limit(speed + MOTOR_DEAD_ZONE, -MAX_SPEED, MAX_SPEED);
    }

    if (speed < 0) {
        return speed_limit(speed - MOTOR_DEAD_ZONE, -MAX_SPEED, MAX_SPEED);
    }

    return 0;
}

static uint16_t Motor_Float_To_PWM(float speed)
{
    if (speed <= 0.0f) {
        return 0;
    }

    if (speed >= (float) MAX_SPEED) {
        return MAX_SPEED;
    }

    return (uint16_t) speed;
}

/* TIM3: 72 MHz / (7999 + 1) = 9 kHz; 比较值 0 ~ 8000 = 占空比 0 ~ 100% */
static void Motor_Set_PWM(uint16_t motor_speed, uint32_t channel)
{
    __HAL_TIM_SET_COMPARE(&htim3, channel, Motor_Limit_PWM(motor_speed));
}

int myabs(int a)
{
    if (a < 0) {
        return -a;
    }

    return a;
}

int16_t speed_limit(int16_t speed, int16_t min, int16_t max)
{
    int16_t temp;

    if (min > max) {
        temp = min;
        min  = max;
        max  = temp;
    }

    if (speed == 0) {
        return 0;
    }

    if (speed < min) {
        return min;
    }

    if (speed > max) {
        return max;
    }

    return speed;
}

void Init_Motor_PWM(void)
{
    Motor_Stop(0);
    HAL_TIM_PWM_Start(&htim3, MOTOR_L_PWM_CHANNEL);
    HAL_TIM_PWM_Start(&htim3, MOTOR_R_PWM_CHANNEL);
}

void PWM_Control_Car(int16_t L_motor_speed, int16_t R_motor_speed)
{
    int16_t sl;
    int16_t sr;

    if (!g_motor_lock) {                    /* 电机锁关: 忽略请求速度, 强制停机 */
        L_control(0, MOTOR_DIR_FORWARD);
        R_control(0, MOTOR_DIR_FORWARD);
        return;
    }

    sl = speed_limit(L_motor_speed, -MAX_SPEED, MAX_SPEED);
    sr = speed_limit(R_motor_speed, -MAX_SPEED, MAX_SPEED);

    sl = Motor_Ignore_Dead_Zone(sl);
    sr = Motor_Ignore_Dead_Zone(sr);

    if (sl < 0) {
        L_control((uint16_t) myabs(sl), MOTOR_DIR_BACK);
    } else {
        L_control((uint16_t) sl, MOTOR_DIR_FORWARD);
    }

    if (sr < 0) {
        R_control((uint16_t) myabs(sr), MOTOR_DIR_BACK);
    } else {
        R_control((uint16_t) sr, MOTOR_DIR_FORWARD);
    }
}

void L_control(uint16_t motor_speed, uint8_t dir)
{
#if MOTOR_L_DIR_INVERT
    dir = (dir == MOTOR_DIR_FORWARD) ? MOTOR_DIR_BACK : MOTOR_DIR_FORWARD;
#endif
    motor_speed = Motor_Limit_PWM(motor_speed);

    if (motor_speed == 0) {
        HAL_GPIO_WritePin(AIN1_GPIO_Port, AIN1_Pin, GPIO_PIN_RESET);
        HAL_GPIO_WritePin(AIN2_GPIO_Port, AIN2_Pin, GPIO_PIN_RESET);
        Motor_Set_PWM(0, MOTOR_L_PWM_CHANNEL);
        return;
    }

    if (dir == MOTOR_DIR_BACK) {
        HAL_GPIO_WritePin(AIN1_GPIO_Port, AIN1_Pin, GPIO_PIN_SET);
        HAL_GPIO_WritePin(AIN2_GPIO_Port, AIN2_Pin, GPIO_PIN_RESET);
    } else {
        HAL_GPIO_WritePin(AIN1_GPIO_Port, AIN1_Pin, GPIO_PIN_RESET);
        HAL_GPIO_WritePin(AIN2_GPIO_Port, AIN2_Pin, GPIO_PIN_SET);
    }

    Motor_Set_PWM(motor_speed, MOTOR_L_PWM_CHANNEL);
}

void R_control(uint16_t motor_speed, uint8_t dir)
{
#if MOTOR_R_DIR_INVERT
    dir = (dir == MOTOR_DIR_FORWARD) ? MOTOR_DIR_BACK : MOTOR_DIR_FORWARD;
#endif
    motor_speed = Motor_Limit_PWM(motor_speed);

    if (motor_speed == 0) {
        HAL_GPIO_WritePin(BIN1_GPIO_Port, BIN1_Pin, GPIO_PIN_RESET);
        HAL_GPIO_WritePin(BIN2_GPIO_Port, BIN2_Pin, GPIO_PIN_RESET);
        Motor_Set_PWM(0, MOTOR_R_PWM_CHANNEL);
        return;
    }

    if (dir == MOTOR_DIR_BACK) {
        HAL_GPIO_WritePin(BIN1_GPIO_Port, BIN1_Pin, GPIO_PIN_SET);
        HAL_GPIO_WritePin(BIN2_GPIO_Port, BIN2_Pin, GPIO_PIN_RESET);
    } else {
        HAL_GPIO_WritePin(BIN1_GPIO_Port, BIN1_Pin, GPIO_PIN_RESET);
        HAL_GPIO_WritePin(BIN2_GPIO_Port, BIN2_Pin, GPIO_PIN_SET);
    }

    Motor_Set_PWM(motor_speed, MOTOR_R_PWM_CHANNEL);
}

void Motor_Stop(uint8_t brake)
{
    if (brake) {
        HAL_GPIO_WritePin(AIN1_GPIO_Port, AIN1_Pin, GPIO_PIN_SET);
        HAL_GPIO_WritePin(AIN2_GPIO_Port, AIN2_Pin, GPIO_PIN_SET);
        HAL_GPIO_WritePin(BIN1_GPIO_Port, BIN1_Pin, GPIO_PIN_SET);
        HAL_GPIO_WritePin(BIN2_GPIO_Port, BIN2_Pin, GPIO_PIN_SET);
        Motor_Set_PWM(MAX_SPEED, MOTOR_L_PWM_CHANNEL);
        Motor_Set_PWM(MAX_SPEED, MOTOR_R_PWM_CHANNEL);
    } else {
        Motor_Set_PWM(0, MOTOR_L_PWM_CHANNEL);
        Motor_Set_PWM(0, MOTOR_R_PWM_CHANNEL);
        HAL_GPIO_WritePin(AIN1_GPIO_Port, AIN1_Pin, GPIO_PIN_RESET);
        HAL_GPIO_WritePin(AIN2_GPIO_Port, AIN2_Pin, GPIO_PIN_RESET);
        HAL_GPIO_WritePin(BIN1_GPIO_Port, BIN1_Pin, GPIO_PIN_RESET);
        HAL_GPIO_WritePin(BIN2_GPIO_Port, BIN2_Pin, GPIO_PIN_RESET);
    }
}

void Motor_Lock_Set(uint8_t on)
{
    g_motor_lock = on ? 1U : 0U;
    if (!g_motor_lock) {
        Motor_Stop(0);      /* 关锁立即滑行停车 */
    }
}

uint8_t Motor_Lock_Get(void)
{
    return g_motor_lock;
}

void Motor_Run(float x, float y)
{
    L_control(Motor_Float_To_PWM(x), MOTOR_DIR_FORWARD);
    R_control(Motor_Float_To_PWM(y), MOTOR_DIR_FORWARD);
}

void Motor_Back(float x, float y)
{
    L_control(Motor_Float_To_PWM(x), MOTOR_DIR_BACK);
    R_control(Motor_Float_To_PWM(y), MOTOR_DIR_BACK);
}

void Motor_Left(float x, float y)
{
    L_control(Motor_Float_To_PWM(x), MOTOR_DIR_BACK);
    R_control(Motor_Float_To_PWM(y), MOTOR_DIR_FORWARD);
    delay_ms(500);
    Motor_Stop(1);
}

void Motor_Right(float x, float y)
{
    L_control(Motor_Float_To_PWM(x), MOTOR_DIR_FORWARD);
    R_control(Motor_Float_To_PWM(y), MOTOR_DIR_BACK);
    delay_ms(500);
    Motor_Stop(1);
}

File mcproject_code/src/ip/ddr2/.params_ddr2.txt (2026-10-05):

PH1P_AXI_CTRL : 0 : U : Dis :  :  : 
PH1P_DDR_TYPE : Integrated : U : En : DDR2;;DDR3;;DDR4;;Integrated :  : 
PH1P_PingPong_PHY : 0 : U : Dis :  :  : 
PH1P_SINGLE_PLL : 0 : U : En :  :  : 
PH1P_REF_CLK : 25.00 : U : En :  : 25 : 400
PH1P_DDR_SPEED : 1066.00 : U : En :  : 400 : 1600
PH1P_DQ_BYTE : 2 : U : Dis : 2 :  : 
PH1P_IO_VOL : 1.5 : U : Dis : 1.5 :  : 
PH1P_VREF : Internal : U : Dis : External;;Internal :  : 
PH1P_PZQ_CAL : 0 : U : Dis :  :  : 
PH1P_PZQ_SHARE : 0 : U : Dis :  :  : 
PH1P_MASTER_BK : BANK11 : U : Dis : BANK11;;BANK12;;BANK13;;BANK14;;BANK32;;BANK33 :  : 
PH1P_COMP_TYPE : x16 : U : Dis : x8;;x16 :  : 
PH1P_COMP_DENSITY : 512 : U : Dis : 512 :  : 
PH1P_SPEED_BIN : DDR2-1066 : U : En : DDR2-1066;;DDR2-1333-8;;DDR2-1333-9 :  : 
GEN_ECC_EN : 0 : G : En :  :  : 
PH1P_MC_EN : 1 : G : En :  :  : 
PH1P_ECC_EN : 0 : G : Dis :  :  : 
MC_ECC : OFF : G : En :  :  : 
PH1P_WDM_WDBI : WDM : U : Dis : WDM :  : 
PH1P_RDBI : NONE : U : Dis : NONE;;RDBI :  : 
PH1P_AXI_ADDR_MAP : ROW_COL_BANK : U : En : BANK_ROW_COL;;ROW_COL_BANK;;ROW_BANK_COL :  : 
MC_ADDR_MAP : ROW_COL_BANK : G : En :  :  : 
PH1P_MC_REORDER : NORMAL : U : En : NORMAL;;STRICT :  : 
MC_REORDER : NORMAL : G : En :  :  : 
PH1P_PLL_LOC : BANK12 : U : Dis : BANK12 :  : 
PH1P_REFCLK_TYPE : NONE : U : Dis : NONE :  : 
GEN_BUFG : 0 : G : En :  :  : 
PH1P_DDR_CS : 1 : U : Dis : 1;;2 :  : 
PH1P_DDR_CK : 1 : U : Dis : 1;;2 :  : 
PH1P_DDR_RESET : 0 : U : Dis : 0 :  : 
PH1P_DDR_CKE : 1 : U : Dis : 1;;2 :  : 
PH1P_DDR_ODT : 1 : U : Dis : 1;;2 :  : 
PH1P_DDR_PARITY : 0 : U : Dis : 0;;1 :  : 
PH1P_DDR_ALERT : 0 : G : Dis :  :  : 
GEN_DUAL_PLL : 1 : G : En :  :  : 
PH1P_TRAINING_EN : 0 : U : Dis :  :  : 
GEN_DELAY_EN : 0 : G : En :  :  : 
GEN_DELAY_B1 : 0 : G : En :  :  : 
GEN_DELAY_B2 : 0 : G : En :  :  : 
GEN_DELAY_B3 : 0 : G : En :  :  : 
GEN_DELAY_B4 : 0 : G : En :  :  : 
GEN_DELAY_B5 : 0 : G : En :  :  : 
GEN_DELAY_B6 : 0 : G : En :  :  : 
GEN_DELAY_B7 : 0 : G : En :  :  : 
GEN_DELAY_B8 : 0 : G : En :  :  : 
PH1P_DELAY_B0 : 1 : G : Dis :  :  : 
PH1P_DELAY_B0_AC : 110 : U : Dis :  : 0 : 2000
PH1P_DELAY_B0_DQ : 110 : U : Dis :  : 0 : 2000
PH1P_DELAY_B1 : 1 : G : Dis :  :  : 
PH1P_DELAY_B1_AC : 110 : U : Dis :  : 0 : 2000
PH1P_DELAY_B1_DQ : 110 : U : Dis :  : 0 : 2000
PH1P_DELAY_B2 : 0 : G : Dis :  :  : 
PH1P_DELAY_B2_AC : 0 : U : Dis :  :  : 
PH1P_DELAY_B2_DQ : 0 : U : Dis :  :  : 
PH1P_DELAY_B3 : 0 : G : Dis :  :  : 
PH1P_DELAY_B3_AC : 0 : U : Dis :  :  : 
PH1P_DELAY_B3_DQ : 0 : U : Dis :  :  : 
PH1P_DELAY_B4 : 0 : G : Dis :  :  : 
PH1P_DELAY_B4_AC : 0 : U : Dis :  :  : 
PH1P_DELAY_B4_DQ : 0 : U : Dis :  :  : 
PH1P_DELAY_B5 : 0 : G : Dis :  :  : 
PH1P_DELAY_B5_AC : 0 : U : Dis :  :  : 
PH1P_DELAY_B5_DQ : 0 : U : Dis :  :  : 
PH1P_DELAY_B6 : 0 : G : Dis :  :  : 
PH1P_DELAY_B6_AC : 0 : U : Dis :  :  : 
PH1P_DELAY_B6_DQ : 0 : U : Dis :  :  : 
PH1P_DELAY_B7 : 0 : G : Dis :  :  : 
PH1P_DELAY_B7_AC : 0 : U : Dis :  :  : 
PH1P_DELAY_B7_DQ : 0 : U : Dis :  :  : 
PH1P_DELAY_B8 : 0 : G : Dis :  :  : 
PH1P_DELAY_B8_AC : 0 : U : Dis :  :  : 
PH1P_DELAY_B8_DQ : 0 : U : Dis :  :  : 
PH1P_MC_AXI : 0 : G : En :  :  : 
GEN_PZQ_SHARE_EN : 0 : G : Dis :  :  : 
GEN_MASTER_BK_EN : 0 : G : Dis :  :  : 
GEN_RDBI_EN : 0 : G : En :  :  : 
GEN_CS_EN : 0 : G : En :  :  : 
GEN_AC_BYTE : 0 : G : En :  :  : 
ENABLE_DDR2 : 0 : G : En :  :  : 
ENABLE_DDR3 : 0 : G : En :  :  : 
ENABLE_DDR4 : 0 : G : En :  :  : 
ENABLE_TWO_TYPE : 1 : G : En :  :  : 
GEN_RESET : 0 : G : En :  :  : 
DEVICE_PH1P100 : 0 : G : En :  :  : 
DEVICE_PH1P50 : 0 : G : En :  :  : 
DEVICE_PH1P35 : 1 : G : En :  :  : 
PH1P_DDRPHY_ROM_INIT : 1 : G : En :  :  : 
PH1P_DDRPHY_ROM_LEN : 1 : G : En :  :  : 
tCK : 1876 : G : En :  :  : 
CS_WIDTH : 1 : G : En :  :  : 
CKE_WIDTH : 1 : G : En :  :  : 
CK_WIDTH : 1 : G : En :  :  : 
ODT_WIDTH : 1 : G : En :  :  : 
BG_WIDTH : 0 : G : En :  :  : 
BA_WIDTH : 2 : G : En :  :  : 
COL_WIDTH : 10 : G : En :  :  : 
ROW_WIDTH : 13 : G : En :  :  : 
ADR_WIDTH : 13 : G : En :  :  : 
PAR_WIDTH : 0 : G : En :  :  : 
PH1P_DDR_CL : 7 : G : Dis :  :  : 
HOST_AC_DRV : 75 : G : En :  :  : 
HOST_DX_DRV : 75 : G : En :  :  : 
HOST_DX_ODT : 75 : G : En :  :  : 
DRAM_DRV : 0 : G : En :  :  : 
DRAM_ODT : 75 : G : En :  :  : 
CL : 7 : G : En :  :  : 
CWL : 6 : U : En : 6 :  : 
DX_NUM : 2 : G : En :  :  : 
DQS_WIDTH : 2 : G : En :  :  : 
DQ_WIDTH : 16 : G : En :  :  : 
DM_WIDTH : 2 : G : En :  :  : 
MC_ADDR_WIDTH : 25 : G : En :  :  : 
MC_DATA_WIDTH : 128 : G : En :  :  : 
MC_MASK_WIDTH : 16 : G : En :  :  : 
PLL_LOCATION : 1 : G : En :  :  : 
PH1P_SYSCLK_LOC : NONE : U : Dis : NONE :  : 
PH1P_IO_ASSIGN :  : U : Dis :  :  : 
PH1P_AC_BYTE : 4 : G : Dis :  :  : 
PH1P_DRC_CHECK : PASS : G : Dis :  :  : 
AC_NUM : 4 : G : En :  :  : 
PLL0_REFCLK_FREQ : 25.0 : G : En :  :  : 
PLL0_REFCLK_DIV : 2 : G : En :  :  : 
PLL0_FBKCLK_DIV : 85 : G : En :  :  : 
PLL0_FRAC : DISABLE : G : En :  :  : 
PLL0_FRAC_SDM : 0 : G : En :  :  : 
PLL0_CLK2_DIV : 2 : G : En :  :  : 
PLL0_CLK3_DIV : 21 : G : En :  :  :
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

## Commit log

2026-10-05 3Dmodels & mspm0code
    [body.stl, body_cover.stl, breast.stl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]
2026-10-05 fpgainit_实时显示
    [.m_params_blk_mem_gen_awb_delay_signal.txt, .m_params_blk_mem_gen_demosaic.txt, .m_params_blk_mem_gen_zhenghe.txt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]
2026-10-08 MCU stm32rct6/mspm0g3507
2026-10-21 fpga避障
2026-10-21 stm32调参
2026-10-25 fpga音频部分正常，霍尔传感器靠近显示屏能显示，喂食音效正常
2026-10-25 三米之内wag
2026-10-28 准备上车调试，音频，视频正常
2026-10-28 3D&项目书
2026-10-29 stm32uwbfollow调参
2026-10-29 基本功能完成，开始调参
2026-10-31 v3针对墙误识别优化
2026-10-31 项目简介readme~❤
2026-11-01 v5：地面识别退回 v1，整理 README 和开发记录
    - 地面识别退回 10-30 的做法，保留尾巴、转弯、狗叫、找出口和提前绕
    - 重写首页 README，压缩 assets 里的大图
    - 更新 FPGA、STM32 README 和相关说明文档
    - 新增 FPGA开发记录.md 和 bit_restore 里的 v5
2026-11-02 技术文档

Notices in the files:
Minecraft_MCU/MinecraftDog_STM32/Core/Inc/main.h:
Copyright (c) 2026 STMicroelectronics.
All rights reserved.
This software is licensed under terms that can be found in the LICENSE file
